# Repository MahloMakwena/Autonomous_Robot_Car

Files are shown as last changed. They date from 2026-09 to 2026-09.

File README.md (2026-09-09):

# Autonomous_Robot_Car
### Autonomous Path-Tracking Robot (RPLIDAR C1)

### Project Overview

This project focuses on designing and programming an **autonomous robotic vehicle** capable of dynamic path tracking, barrier mapping, and high-speed obstacle avoidance. Built on the **ESP32-S3 microcontroller architecture**, the robot uses real-time laser scanning data to safely navigate complex tracks without human intervention. 

###  How It Works

### 1. Environmental Mapping (The "Eyes")

* **Component:** Slamtec RPLIDAR C1 (2D DTOF Laser Scanner)
* **Execution:** The LiDAR emits thousands of laser pulses per second in a continuous **360-degree flat sweep**. It creates a real-time 2D coordinates map of track boundaries, walls, and upcoming curves up to 12 metres away.

### 2. Intelligent Path Decision (The "Brain")

* **Component:** ESP32-S3 Dual-Core Processor
* **Execution:** The processor ingests the live LiDAR data stream to calculate clear pathways ("gap finding"). Using an optimized navigation algorithm, the software dynamically adjusts steering vectors to guide the vehicle along the safest, fastest racing line.

### 3. Fail-Safe Emergency Cutoff (The "Shield")

* **Component:** 3-Button Hardware Latching Circuit & Interrupt Watchdog [disclaimer]
* **Execution:** For ultimate physical safety, the robot implements a true **hardware-level E-Stop loop**. Pressing the manual E-stop button breaks a self-holding relay circuit to instantly cut 100% of electrical power to the drive motors. Simultaneously, an isolated **3.3V logic signal** triggers a high-priority hardware interrupt on the ESP32-S3, forcing the software into a permanent safe halt mode until an engineer performs a manual system reset.

###  Tech Stack & Tools

* **Programming Language:** C++ (Embedded)
* **Framework:** Arduino IDE (ESP32 Arduino Core)
* **Hardware Design & Simulation:** Cirkit Designer

###  System Simulation & Architecture

To ensure high-fidelity safety testing before deploying code onto physical hardware, the system architecture was completely mapped out and simulated using **Cirkit Designer**: 

1. **The Latching Safety Loop:** We simulated a self-holding hardware latch circuit using standard DC relay modules, a Normally Closed (NC) button, and a Normally Open (NO) button. This layout guarantees power is cut mechanically to the motors during an emergency, entirely bypassing the processor.
2. **Logic Monitoring:** An isolated 3.3V logic line is mapped from the ESP32-S3 through a separate signal switch to GPIO 4, stabilized by a physical 10kΩ pull-down resistor to prevent pin floatation.
3. **Firmware Integration:** The Arduino sketch utilizes the Xtensa dual-core architecture of the ESP32-S3 to register a high-priority hardware interrupt (IRAM_ATTR). The software instantly drops the vehicle into a permanent safe state the exact millisecond a hardware shutdown occurs.

### ⚙️ Repository Structure

* **/src**: Core C++ firmware for the ESP32-S3, managing the hardware interrupt loops, LiDAR data parsing, and path-tracking logic.
* **/schematics**: Complete visual wiring blueprints and architecture maps designed in **Cirkit Designer**.

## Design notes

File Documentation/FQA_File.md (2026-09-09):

# Robo Rumble: Facilitator Q&A (FQ&A) Attendance Logbook

**Team Name:** Uniq
**Category:** Robo Grand Prix

*Instructions: To qualify for the 10 Bonus Points, log your attendance for every FQ&A session below. You must include a direct link to a screenshot proving your attendance (e.g., a screenshot of the meeting lobby or chat with your username visible).*

## Attendance Log

| Session Date | Time (Start-End) | Facilitator Name/Username | Our Key Takeaway / Question Asked | Proof of Attendance (Screenshot) |
| :--- | :--- | :--- | :--- | :--- |
| 2026-05-24 | 17:32 - 20:21 | senzo / VARZA | Asked about next steps after registration for Grand Prix car racing competition and whether we must buy own components or university will provide. Facilitator directed us to welcome channel in Robo Rumble Server. Clarified that we can start building after exams as Computer Systems Engineering TUT student. | [Link to image in repo](./FQA_Proof/senzo_chat.png) |
| 2026-08-28 | 20:04 - 20:04 | Donnel.M | Asked if Grand Prix challenge racing robots will race inside a walled path. Confirmed yes - robots will be placed inside walled path from start to finish line. This validated our wall-following + path tracking design with RPLidar C1 / Ultrasonic + Servo approach. | [Link to image in repo](./FQA_Proof/donnel_chat.png) |
| 2026-08-28 | 20:10 - 06:36 | +27 73 828 6493 (Robo Labs Bootcamp Facilitator) | Attended bootcamp on campus (TUT) and asked about Grand Prix walled path from start to finish line. Facilitator confirmed Yes. | [Link to image in repo](./FQA_Proof/whatsapp_bootcamp.png) |
| 2026-09-02 | 19:29 - 13:32 | Donnel.M / senzo | Asked if CAD design must be built from scratch or if we can assemble downloaded files from open source (A2Plus workbench). Facilitator advised to ask Robo Labs for final ruling. Takeaway: We will design custom U-brackets for JGB37 motors from scratch but can use open-source ESP32-S3 and L298N models with attribution. | [Link to image in repo](./FQA_Proof/donnel_chat.png) |

---

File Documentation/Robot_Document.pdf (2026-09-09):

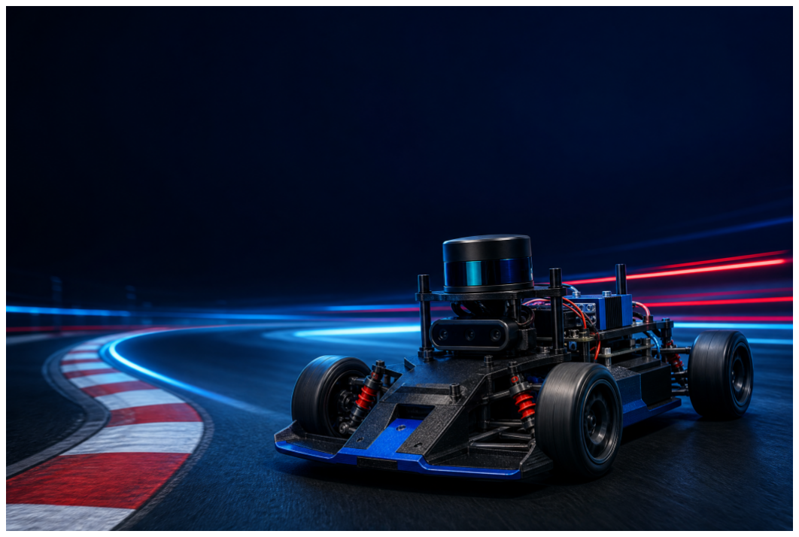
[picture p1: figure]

AUTONOMOUS RACING CAR • ESP32-S3 PROJECT REPORT • 2026

# AUTONOMOUS RACING CAR

Smart Sensors | Intelligent Control | Faster Tomorrow

## A 3D-Printed ESP32-S3 Autonomous Racing Car

Design, Build and Programming Documentation

Project Name : Autonomous Racing Car Main Controller : ESP32-S3
Course : Robotics & Embedded Systems Year : 2026

# Table of Contents

### 1. Project Overview 2. Objectives 3. Hardware Components 4. Bill of Materials 5. Software Requirements 6. System Architecture 7. Main Features 8. Project Structure 9. Installation Guide 10. Code Instructions 11. How to Run 12. Safety Notes 13. Future Improvements 14. Authors

## 1. Project Overview

The Autonomous Racing Car is an intelligent robotic vehicle designed to navigate a race track without continuous human control. It uses an ESP32-S3 as the main controller to process sensor information, control the motors, detect obstacles, calculate distances, and make decisions while racing.
The system combines a 360° LiDAR, wheel encoders, IMU, motor driver, steering servo and other sensors to allow the car to navigate safely and efficiently.
Key Idea
“Smart technology, precision control, maximum performance.”

## 2. Objectives

- Build a fully autonomous racing car.
- Use a 360° LiDAR to detect obstacles and other racing cars.
- Measure the distance between the car and obstacles.
- Calculate the distance traveled by the car using wheel encoders.
- Determine when the car needs to slow down before a turn.
- Automatically control steering and motor speed.
- Detect and avoid collisions.
- Navigate different turns on the racing track.
- Use the ESP32-S3 to control the complete system.
- Develop a reliable and responsive autonomous control system.

## 3. Hardware Components

- ESP32-S3 Development Board
- 360° LiDAR Sensor
- Motor Driver (L298N)
- DC Geared Motor (6V)
- Wheel Encoder
- IMU Sensor (MPU6050)
- Steering Servo Motor
- Ultrasonic Sensor (HC-SR04)
- Emergency-Stop Button
- Power Button
- Rechargeable Battery (7.4V/11.1V)
- Buck Converter (5V/3A)
- Wheels (x4)
- 3D-Printed Chassis
- Jumper Wires & Connectors

COMPONENT COSTING

## 4. Bill of Materials

No. | Component | Part Number / Model | Supplier | Qty | Unit Price (ZAR) | Total (ZAR)
1 | ESP32-S3 Dev Board | ESP32-S3-WROOM-1 | Seeed Studio | 1 | R 250 | R 250
2 | 360° LiDAR | RPLIDAR A1 | RobotShop | 1 | R 1,800 | R 1,800
3 | Motor Driver | L298N | Amazon | 1 | R 120 | R 120
4 | DC Geared Motor | TT 6V | Amazon | 2 | R 150 | R 300
5 | Wheel Encoder | QTR-8RC | RobotShop | 2 | R 100 | R 200
6 | IMU Sensor | MPU6050 | Amazon | 1 | R 80 | R 80
7 | Steering Servo | SG90 | Amazon | 1 | R 150 | R 150
8 | Ultrasonic Sensor | HC-SR04 | Amazon | 1 | R 70 | R 70
9 | Emergency-Stop | 22mm | RS Components | 1 | R 90 | R 90
10 | Power Button | PBS-110 | Amazon | 1 | R 50 | R 50
11 | Rechargeable Battery | 7.4V 2200mAh | Amazon | 1 | R 350 | R 350
12 | Buck Converter | LM2596 | Takealot | 1 | R 60 | R 60
13 | Wheels | 66mm | Takealot | 4 | R 60 | R 240
14 | 3D-Printed Chassis | Custom | Self-Design | 1 | R 400 | R 400
15 | Wires/Connectors | Jumper Kit | Takealot | 1 set | R 150 | R 150
Grand Total | | | | | | R 4,310

## 5. Software Requirements

- Arduino IDE
- ESP32 board support package
- C/C++ programming language
- LiDAR library / driver
- Servo motor library
- Encoder processing code
- IMU library
- Serial Monitor for debugging
- Git / GitHub (optional)

CONTROL SYSTEM

## 6. System Architecture

The ESP32-S3 acts as the main controller. It receives input from the 360° LiDAR (obstacle detection), wheel encoders (distance & speed), the IMU (orientation), and an ultrasonic sensor (backup). Based on this sensor data, it drives three outputs: the steering servo (angle control), the motor driver / DC motors (drive the wheels), and the emergency-stop system (safety).

AUTONOMY CAPABILITIES

## 7. Main Features

### Obstacle Detection

360° LiDAR continuously scans the surroundings and provides distance measurements.

### Distance Measurement

LiDAR measures distance to objects, while wheel encoders track how far the car has traveled.

### Automatic Steering

ESP32-S3 controls the steering servo according to the detected track direction.

### Speed Control

Motor speed is reduced before a turn or obstacle and increased after the turn.

### Collision Avoidance

Detects obstacles or other cars and takes action (slow down or change direction).

### Emergency Stop

Immediately disables the motors if an unsafe situation occurs.

SOFTWARE ORGANISATION

## 8. Project Structure

Autonomous-Racing-Car/
├── src/
│ └── main.cpp
├── sensors/
│ | ├── lidar.cpp
│ | ├── encoder.cpp
│ | ├── imu.cpp
│ | └── ultrasonic.cpp
├── motors/
│ | ├── motor_control.cpp
│ | └── steering.cpp
├── control/
│ | ├── obstacle_avoidance.cpp
│ | ├── speed_control.cpp
│ | └── turn_control.cpp
├── wiring/
│ └── wiring_diagram.png
├── CAD/
│ └── chassis/
└── documentation/
| └── project_report.pdf

SETUP WORKFLOW

## 9. Installation Guide

1. Install Arduino IDE — Download and install the Arduino IDE.
2. Add ESP32 Support — Open File → Preferences → Add Board Manager URL: https://dl.espressif.com/dl/package_esp32_index.json
3. Install ESP32 Board Package — Tools → Board → Boards Manager → Search for ESP32 and install.
4. Select the Board — Tools → Board → ESP32-S3 Dev Module.
5. Connect the ESP32-S3 — Use a USB cable.
6. Install Required Libraries — LiDAR, Servo, Encoder, Motor control.
7. Upload the Program — Open src/main.cpp, compile and upload.

CONTROL LOOP

## 10. Code Instructions

void loop() {
readLiDAR();
readEncoders();
readIMU();

calculateDistance();
calculateSpeed();

detectObstacles();
determineTurn();

controlSteering();
controlMotor();

checkEmergencyStop();
}
The ESP32-S3 repeatedly:
8. Reads the sensors
9. Calculates distances
10. Calculates speed and distance
11. Detects obstacles
12. Determines if a turn is approaching
13. Adjusts steering
14. Adjusts motor speed
15. Checks the emergency-stop system

TEST PROCEDURE

## 11. How to Run

- Place the car on a safe test surface.
- Check all wiring.
- Verify LiDAR data.
- Check wheel encoders.
- Test steering servo.
- Test motor driver (wheels lifted).
- Test emergency-stop button.
- Upload the program.
- Start the system.
- Begin at low speed.
- Increase speed after verifying all systems.

SAFE OPERATION

## 12. Safety Notes

- Always test at low speed first.
- Keep hands away from rotating wheels.
- Do not test near people, roads or hazards.
- Test the emergency-stop button.
- Ensure battery voltage is suitable.
- Do not connect motors to ESP32 GPIO pins directly.
- Use an appropriate motor driver.
- Make sure LiDAR and sensors are secure.
- Check for loose wires before every test.
- Disconnect the battery before changing wiring.
- Use proper battery protection.
- Never leave the car running unattended.

NEXT LAP

## 13. Future Improvements

- Higher-resolution LiDAR.
- Faster motor drivers.
- Better wheel encoders.
- GPS for outdoor navigation.
- Camera-based track recognition.
- Machine-learning obstacle detection.
- PID speed control.
- PID steering control.
- Automatic racing-line optimization.
- Wireless monitoring (phone/computer).
- Real-time telemetry.
- Automatic lap counting.
- Improved battery management.
- More advanced collision prediction.

PROJECT TEAM

## 14. Authors

Name | Role
| Project Lead
| Hardware & Electronics
| Software & Programming
| Mechanical / CAD Design
| Testing & Documentation
Institution: ______________________________
Course / Department: ______________________________ Year: 2026

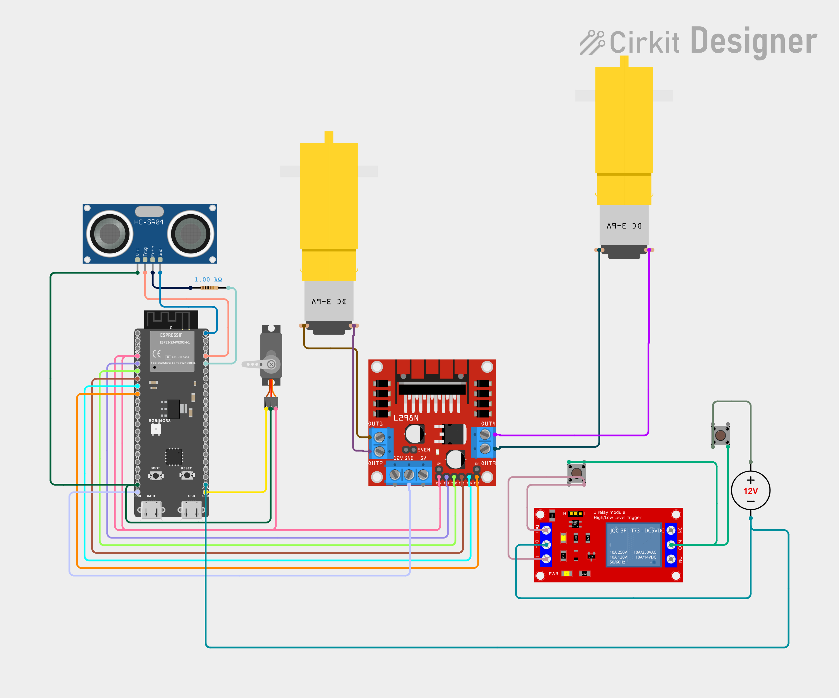
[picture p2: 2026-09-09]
CAD Designs/circuit_image.png

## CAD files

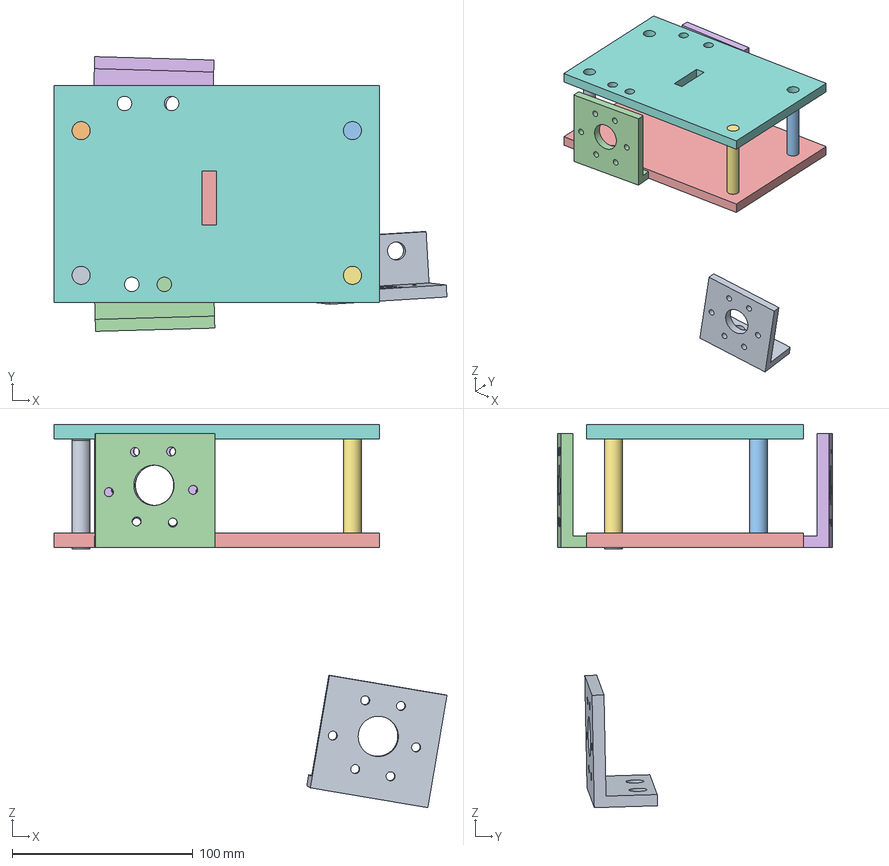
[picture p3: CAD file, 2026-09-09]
CAD Designs/Assembly.FCStd
217.3 x 151.9 x 211.9 mm
Screws_001
Screws_002
Screws_004
Motor_Mount_009
Chassis_Plate_004
Motor_Mount_011
Screws_006
Top_Chassis_001
Motor_Mount_014

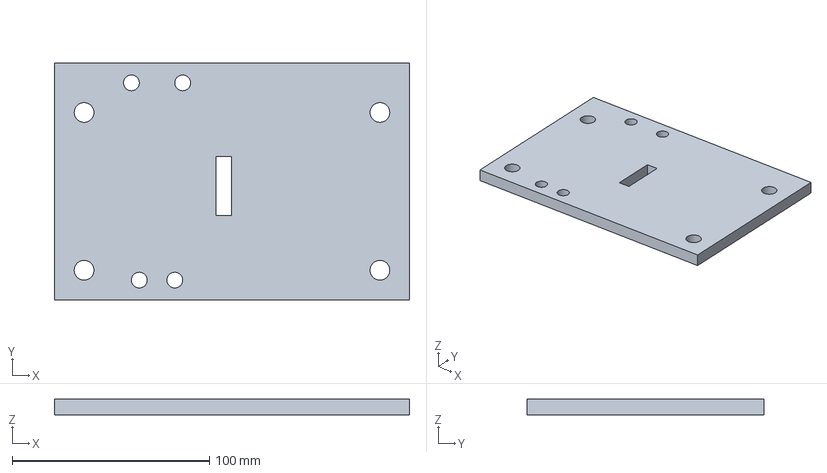
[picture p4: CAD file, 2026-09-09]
CAD Designs/Top_Chassis.FCStd
180.0 x 120.0 x 8.00 mm

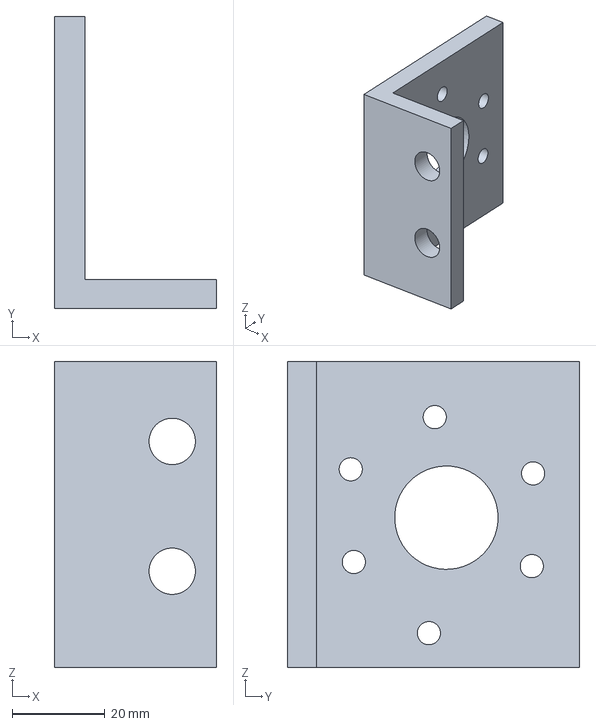
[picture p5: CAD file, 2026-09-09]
CAD Designs/Motor_Mount.FCStd
35.0 x 63.0 x 66.0 mm

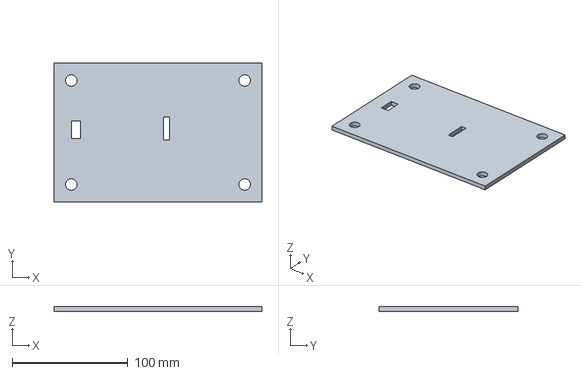
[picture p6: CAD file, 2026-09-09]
CAD Designs/Designed_Robot.FCStd
180.0 x 120.0 x 4.00 mm

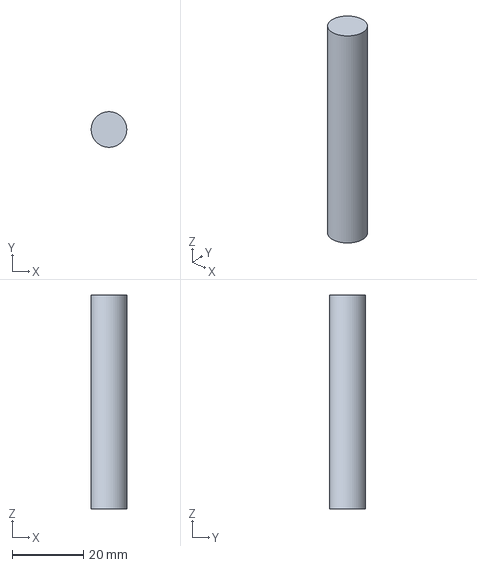
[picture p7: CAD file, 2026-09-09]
CAD Designs/Screws.FCStd
9.99 x 10.00 x 60.0 mm

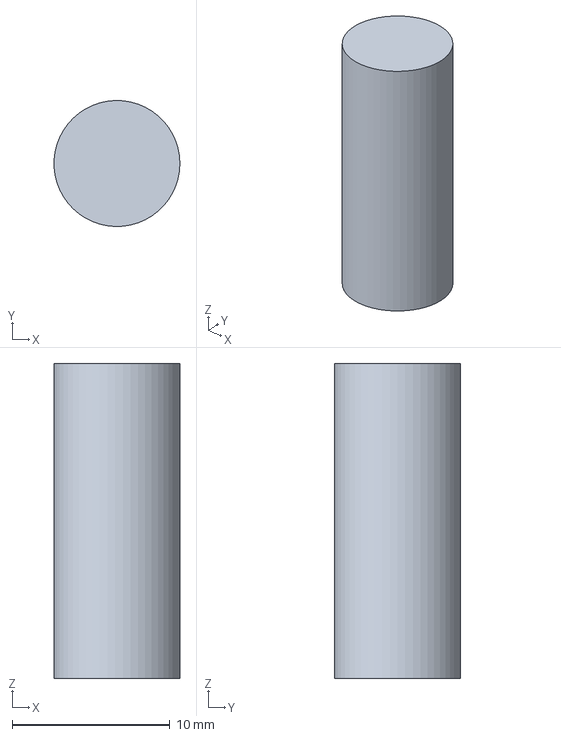
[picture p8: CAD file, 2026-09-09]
CAD Designs/small_screws.FCStd
7.99 x 8.00 x 20.0 mm

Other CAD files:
CAD Designs/Chassis_Plate.FCStd

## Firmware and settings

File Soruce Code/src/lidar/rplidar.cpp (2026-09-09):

/*
====================================================================
                 AUTONOMOUS RACING CAR
                     ESP32-S3 + RPLIDAR A1
====================================================================
*/

#include <Arduino.h>
#include <ESP32Servo.h>

// MOTOR PINS
const int LEFT_MOTOR_IN1 = 5;
const int LEFT_MOTOR_IN2 = 6;
const int LEFT_MOTOR_PWM = 7;
const int RIGHT_MOTOR_IN1 = 9;
const int RIGHT_MOTOR_IN2 = 10;
const int RIGHT_MOTOR_PWM = 8;

// STEERING
const int STEERING_SERVO_PIN = 4;
Servo steeringServo;
const int STEERING_CENTER = 90;
const int STEERING_LEFT = 55;
const int STEERING_RIGHT = 125;

// BUTTONS
const int START_BUTTON = 11;
const int POWER_BUTTON = 12;
const int ESTOP_BUTTON = 13;

// ENCODERS
const int LEFT_ENCODER_PIN = 14;
const int RIGHT_ENCODER_PIN = 15;
volatile long leftEncoderTicks = 0;
volatile long rightEncoderTicks = 0;

// RPLIDAR A1 UART
const int LIDAR_RX_PIN = 16;
const int LIDAR_TX_PIN = 17;
HardwareSerial LidarSerial(1);
const uint32_t LIDAR_BAUD = 115200;

// RPLIDAR COMMANDS
const uint8_t RPLIDAR_CMD_STOP = 0x25;
const uint8_t RPLIDAR_CMD_SCAN = 0x20;
const uint8_t RPLIDAR_CMD_RESET = 0x40;

// ENCODER SETTINGS
const float TICKS_PER_REVOLUTION = 20.0;
const float WHEEL_DIAMETER_MM = 65.0;
const float WHEEL_CIRCUMFERENCE_MM = PI * WHEEL_DIAMETER_MM;

// SPEED SETTINGS
int currentSpeed = 0;
const int MIN_SPEED = 80;
const int MAX_SPEED = 255;
const int ACCELERATION_STEP = 2;
const int DECELERATION_STEP = 8;

// LiDAR SETTINGS
const float SAFE_DISTANCE_CM = 50.0;
const float SLOW_DISTANCE_CM = 100.0;
const float TURN_DISTANCE_CM = 150.0;

// LiDAR DATA
float lidarDistance[360];
unsigned long lidarLastUpdate[360];

float frontDistance = 999.0;
float leftDistance = 999.0;
float rightDistance = 999.0;
float rearDistance = 999.0;

// RACING DATA
float totalDistance = 0.0;
float currentSpeedKmh = 0.0;

// CAR STATE
bool powerOn = false;
bool carRunning = false;
bool emergencyStop = false;
bool obstacleDetected = false;
bool turnAhead = false;

// TIMERS
unsigned long lastSpeedCalculation = 0;
unsigned long lastSensorAnalysis = 0;
unsigned long lastPrint = 0;

void IRAM_ATTR leftEncoderISR() {
    leftEncoderTicks++;
}

void IRAM_ATTR rightEncoderISR() {
    rightEncoderTicks++;
}

void setup() {
    Serial.begin(115200);
    delay(500);

    Serial.println();
    Serial.println("========================================");
    Serial.println("       AUTONOMOUS RACING CAR");
    Serial.println("       ESP32-S3 + RPLIDAR A1");
    Serial.println("========================================");

    initializePins();
    initializeMotors();
    initializeSteering();
    initializeEncoders();
    initializeButtons();
    initializeLidar();

    stopCar();
    centerSteering();

    Serial.println();
    Serial.println("SYSTEM READY");
    Serial.println("Press POWER button.");
}

void loop() {
    checkEmergencyStop();

    if (emergencyStop) {
        emergencyBrake();
        return;
    }

    checkPowerButton();

    if (!powerOn) {
        stopCar();
        return;
    }

    checkStartButton();

    if (!carRunning) {
        stopCar();
        return;
    }

    processLidar();
    updateEncoderDistance();
    calculateSpeed();

    if (millis() - lastSensorAnalysis >= 50) {
        lastSensorAnalysis = millis();
        updateDirectionDistances();
        detectObstacles();
        detectTurn();
    }

    autonomousDrive();
    printSensorData();

    delay(2);
}

void initializePins() {
    pinMode(LEFT_MOTOR_IN1, OUTPUT);
    pinMode(LEFT_MOTOR_IN2, OUTPUT);
    pinMode(RIGHT_MOTOR_IN1, OUTPUT);
    pinMode(RIGHT_MOTOR_IN2, OUTPUT);
    pinMode(LEFT_MOTOR_PWM, OUTPUT);
    pinMode(RIGHT_MOTOR_PWM, OUTPUT);
    Serial.println("Pins initialized.");
}

void initializeMotors() {
    ledcAttach(LEFT_MOTOR_PWM, 1000, 8);
    ledcAttach(RIGHT_MOTOR_PWM, 1000, 8);
    stopCar();
    Serial.println("Motors initialized.");
}

void initializeSteering() {
    steeringServo.attach(STEERING_SERVO_PIN);
    steeringServo.write(STEERING_CENTER);
    Serial.println("Steering initialized.");
}

void initializeEncoders() {
    pinMode(LEFT_ENCODER_PIN, INPUT_PULLUP);
    pinMode(RIGHT_ENCODER_PIN, INPUT_PULLUP);

    attachInterrupt(digitalPinToInterrupt(LEFT_ENCODER_PIN), leftEncoderISR, RISING);
    attachInterrupt(digitalPinToInterrupt(RIGHT_ENCODER_PIN), rightEncoderISR, RISING);

    Serial.println("Encoders initialized.");
}

void initializeButtons() {
    pinMode(START_BUTTON, INPUT_PULLUP);
    pinMode(POWER_BUTTON, INPUT_PULLUP);
    pinMode(ESTOP_BUTTON, INPUT_PULLUP);
    Serial.println("Buttons initialized.");
}

void initializeLidar() {
    LidarSerial.begin(
        LIDAR_BAUD,
        SERIAL_8N1,
        LIDAR_RX_PIN,
        LIDAR_TX_PIN
    );

    delay(100);

    while (LidarSerial.available()) {
        LidarSerial.read();
    }

    rplidarStop();
    delay(100);
    rplidarStart();

    Serial.println("RPLIDAR A1 initialized.");
}

void rplidarStop() {
    uint8_t command[] = {0xA5, RPLIDAR_CMD_STOP};
    LidarSerial.write(command, sizeof(command));
    LidarSerial.flush();
}

void rplidarReset() {
    uint8_t command[] = {0xA5, RPLIDAR_CMD_RESET};
    LidarSerial.write(command, sizeof(command));
    LidarSerial.flush();
    delay(100);
}

void rplidarStart() {
    uint8_t command[] = {0xA5, RPLIDAR_CMD_SCAN};
    LidarSerial.write(command, sizeof(command));
    LidarSerial.flush();
    delay(100);
}

void processLidar() {
    static uint8_t packet[5];
    static uint8_t packetIndex = 0;

    while (LidarSerial.available()) {
        uint8_t b = LidarSerial.read();

        if (packetIndex == 0) {
            if ((b & 0x01) == 0) {
                continue;
            }

            packet[0] = b;
            packetIndex = 1;
            continue;
        }

        packet[packetIndex] = b;
        packetIndex++;

        if (packetIndex >= 5) {
            packetIndex = 0;

            bool startBit = packet[0] & 0x01;
            bool inverseStartBit = packet[0] & 0x02;

            if (startBit == inverseStartBit) {
                continue;
            }

            uint8_t quality = packet[0] >> 2;

            if (quality == 0) {
                continue;
            }

            uint16_t angleRaw =
                packet[1] |
                (packet[2] << 8);

            float angle = (angleRaw >> 1) / 64.0;

            uint16_t distanceRaw =
                packet[3] |
                (packet[4] << 8);

            float distanceMM = distanceRaw / 4.0;
            float distanceCM = distanceMM / 10.0;

            if (angle < 0 || angle >= 360) {
                continue;
            }

            if (distanceCM <= 0 || distanceCM > 1200) {
                continue;
            }

            int index = (int)angle;

            if (index >= 0 && index < 360) {
                lidarDistance[index] = distanceCM;
                lidarLastUpdate[index] = millis();
            }
        }
    }
}

float getDistanceAtAngle(int angle) {
    angle = angle % 360;

    if (angle < 0) {
        angle += 360;
    }

    if (millis() - lidarLastUpdate[angle] > 500) {
        return 999.0;
    }

    return lidarDistance[angle];
}

float getMinimumDistance(int startAngle, int endAngle) {
    float minimumDistance = 999.0;

    if (startAngle <= endAngle) {
        for (int angle = startAngle; angle <= endAngle; angle++) {
            float distance = getDistanceAtAngle(angle);

            if (distance < minimumDistance) {
                minimumDistance = distance;
            }
        }
    } else {
        for (int angle = startAngle; angle < 360; angle++) {
            float distance = getDistanceAtAngle(angle);

            if (distance < minimumDistance) {
                minimumDistance = distance;
            }
        }

        for (int angle = 0; angle <= endAngle; angle++) {
            float distance = getDistanceAtAngle(angle);

            if (distance < minimumDistance) {
                minimumDistance = distance;
            }
        }
    }

    return minimumDistance;
}

void updateDirectionDistances() {
    frontDistance = getMinimumDistance(345, 15);
    rightDistance = getMinimumDistance(75, 105);
    rearDistance = getMinimumDistance(165, 195);
    leftDistance = getMinimumDistance(255, 285);
}

void detectObstacles() {
    obstacleDetected = frontDistance <= SAFE_DISTANCE_CM;
}

void detectTurn() {
    if (frontDistance < TURN_DISTANCE_CM) {
        turnAhead =
            leftDistance > frontDistance + 20 ||
            rightDistance > frontDistance + 20;
    } else {
        turnAhead = false;
    }
}

void setMotorPWM(int leftPWM, int rightPWM) {
    leftPWM = constrain(leftPWM, 0, 255);
    rightPWM = constrain(rightPWM, 0, 255);

    ledcWrite(LEFT_MOTOR_PWM, leftPWM);
    ledcWrite(RIGHT_MOTOR_PWM, rightPWM);
}

void moveForward(int speed) {
    speed = constrain(speed, 0, 255);

    digitalWrite(LEFT_MOTOR_IN1, HIGH);
    digitalWrite(LEFT_MOTOR_IN2, LOW);

    digitalWrite(RIGHT_MOTOR_IN1, HIGH);
    digitalWrite(RIGHT_MOTOR_IN2, LOW);

    setMotorPWM(speed, speed);
}

void moveReverse(int speed) {
    speed = constrain(speed, 0, 255);

    digitalWrite(LEFT_MOTOR_IN1, LOW);
    digitalWrite(LEFT_MOTOR_IN2, HIGH);

    digitalWrite(RIGHT_MOTOR_IN1, LOW);
    digitalWrite(RIGHT_MOTOR_IN2, HIGH);

    setMotorPWM(speed, speed);
}

void stopCar() {
    setMotorPWM(0, 0);

    digitalWrite(LEFT_MOTOR_IN1, LOW);
    digitalWrite(LEFT_MOTOR_IN2, LOW);

    digitalWrite(RIGHT_MOTOR_IN1, LOW);
    digitalWrite(RIGHT_MOTOR_IN2, LOW);
}

void steerLeft() {
    steeringServo.write(STEERING_LEFT);
}

void steerRight() {
    steeringServo.write(STEERING_RIGHT);
}

void centerSteering() {
    steeringServo.write(STEERING_CENTER);
}

void turnLeft(int speed) {
    steerLeft();
    moveForward(speed);
}

void turnRight(int speed) {
    steerRight();
    moveForward(speed);
}

void increaseSpeed() {
    currentSpeed += ACCELERATION_STEP;

    if (currentSpeed > MAX_SPEED) {
        currentSpeed = MAX_SPEED;
    }
}

void decreaseSpeed() {
    currentSpeed -= DECELERATION_STEP;

    if (currentSpeed < MIN_SPEED) {
        currentSpeed = MIN_SPEED;
    }
}

void emergencyBrake() {
    currentSpeed = 0;
    stopCar();
    centerSteering();
}

void controlSpeed() {
    if (frontDistance <= SAFE_DISTANCE_CM) {
        currentSpeed = 0;
        return;
    }

    if (frontDistance <= SLOW_DISTANCE_CM) {
        decreaseSpeed();
        return;
    }

    if (turnAhead) {
        decreaseSpeed();
        return;
    }

    increaseSpeed();
}

void updateEncoderDistance() {
    static long previousLeftTicks = 0;
    static long previousRightTicks = 0;

    long leftTicks;
    long rightTicks;

    noInterrupts();
    leftTicks = leftEncoderTicks;
    rightTicks = rightEncoderTicks;
    interrupts();

    long leftDifference = leftTicks - previousLeftTicks;
    long rightDifference = rightTicks - previousRightTicks;

    previousLeftTicks = leftTicks;
    previousRightTicks = rightTicks;

    float averageTicks =
        (leftDifference + rightDifference) / 2.0;

    float revolutions =
        averageTicks / TICKS_PER_REVOLUTION;

    float distanceMM =
        revolutions * WHEEL_CIRCUMFERENCE_MM;

    totalDistance += distanceMM / 1000.0;
}

void calculateSpeed() {
    unsigned long now = millis();

    if (now - lastSpeedCalculation < 100) {
        return;
    }

    static float previousDistance = 0;

    float distanceDifference =
        totalDistance - previousDistance;

    previousDistance = totalDistance;

    currentSpeedKmh =
        distanceDifference * 10.0 * 3.6;

    lastSpeedCalculation = now;
}

void resetDistance() {
    totalDistance = 0;

    noInterrupts();
    leftEncoderTicks = 0;
    rightEncoderTicks = 0;
    interrupts();

    Serial.println("Distance reset.");
}

int chooseAvoidanceDirection() {
    if (
        leftDistance > SAFE_DISTANCE_CM &&
        leftDistance > rightDistance
    ) {
        return -1;
    }

    if (
        rightDistance > SAFE_DISTANCE_CM &&
        rightDistance > leftDistance
    ) {
        return 1;
    }

    if (leftDistance > SAFE_DISTANCE_CM) {
        return -1;
    }

    if (rightDistance > SAFE_DISTANCE_CM) {
        return 1;
    }

    return 0;
}

void avoidObstacle() {
    currentSpeed = MIN_SPEED;

    int direction = chooseAvoidanceDirection();

    if (direction == -1) {
        Serial.println("OBSTACLE -> LEFT");
        steerLeft();
        moveForward(MIN_SPEED);
    } else if (direction == 1) {
        Serial.println("OBSTACLE -> RIGHT");
        steerRight();
        moveForward(MIN_SPEED);
    } else {
        Serial.println("OBSTACLE -> STOP");
        emergencyBrake();
    }
}

void handleTurn() {
    if (leftDistance > rightDistance) {
        turnLeft(currentSpeed);
    } else {
        turnRight(currentSpeed);
    }
}

void autonomousDrive() {
    if (emergencyStop) {
        emergencyBrake();
        return;
    }

    if (frontDistance <= SAFE_DISTANCE_CM) {
        emergencyBrake();
        avoidObstacle();
        return;
    }

    if (turnAhead) {
        controlSpeed();
        handleTurn();
        return;
    }

    controlSpeed();

    centerSteering();
    moveForward(currentSpeed);
}

void checkStartButton() {
    static bool lastState = HIGH;

    bool state = digitalRead(START_BUTTON);

    if (lastState == HIGH && state == LOW) {
        if (powerOn && !emergencyStop) {
            carRunning = !carRunning;

            if (carRunning) {
                currentSpeed = MIN_SPEED;
                Serial.println("RACING STARTED");
            } else {
                currentSpeed = 0;
                stopCar();
                centerSteering();
                Serial.println("RACING STOPPED");
            }
        }

        delay(50);
    }

    lastState = state;
}

void checkPowerButton() {
    static bool lastState = HIGH;

    bool state = digitalRead(POWER_BUTTON);

    if (lastState == HIGH && state == LOW) {
        powerOn = !powerOn;

        if (powerOn) {
            Serial.println("POWER ON");
            currentSpeed = 0;
        } else {
            Serial.println("POWER OFF");
            carRunning = false;
            currentSpeed = 0;
            stopCar();
            centerSteering();
        }

        delay(50);
    }

    lastState = state;
}

void checkEmergencyStop() {
    if (digitalRead(ESTOP_BUTTON) == LOW) {
        if (!emergencyStop) {
            emergencyStop = true;
            carRunning = false;
            currentSpeed = 0;
            stopCar();
            centerSteering();

            Serial.println();
            Serial.println("!!!!!!!!!!!!!!!!!!!!!!!!");
            Serial.println("!!! EMERGENCY STOP !!!");
            Serial.println("!!!!!!!!!!!!!!!!!!!!!!!!");
        }
    }
}

void resetEmergencyStop() {
    if (digitalRead(ESTOP_BUTTON) == HIGH) {
        emergencyStop = false;
        currentSpeed = 0;
        centerSteering();
        Serial.println("Emergency stop reset.");
    }
}

void printSensorData() {
    unsigned long now = millis();

    if (now - lastPrint < 500) {
        return;
    }

    lastPrint = now;

    Serial.println();
    Serial.println("================================");
    Serial.println("          CAR STATUS");
    Serial.println("================================");

    Serial.print("Power: ");
    Serial.println(powerOn ? "ON" : "OFF");

    Serial.print("Running: ");
    Serial.println(carRunning ? "YES" : "NO");

    Serial.print("Emergency: ");
    Serial.println(emergencyStop ? "YES" : "NO");

    Serial.println("--------------------------------");

    Serial.print("Front: ");
    Serial.print(frontDistance, 1);
    Serial.println(" cm");

    Serial.print("Left: ");
    Serial.print(leftDistance, 1);
    Serial.println(" cm");

    Serial.print("Right: ");
    Serial.print(rightDistance, 1);
    Serial.println(" cm");

    Serial.print("Rear: ");
    Serial.print(rearDistance, 1);
    Serial.println(" cm");

    Serial.println("--------------------------------");

    Serial.print("Distance: ");
    Serial.print(totalDistance, 3);
    Serial.println(" m");

    Serial.print("Speed: ");
    Serial.print(currentSpeedKmh, 2);
    Serial.println(" km/h");

    Serial.print("Motor PWM: ");
    Serial.println(currentSpeed);

    Serial.print("Obstacle: ");
    Serial.println(obstacleDetected ? "YES" : "NO");

    Serial.print("Turn: ");
    Serial.println(turnAhead ? "YES" : "NO");

    Serial.println("================================");
}

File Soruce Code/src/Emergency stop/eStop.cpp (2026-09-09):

void loop() {
      // Check if the hardware interrupt flag was tripped
  if (estopTriggered) 
  {
    // 1. Instantly write software failsafes (e.g., turn off software PWM signals)
        analogWrite(motorPin1, 0); 
        analogWrite(motorPin2, 0); 
    // 2. Lock the software loop permanently until an engineer resets the board
    while (true) 
    {
      Serial.println("!!! SOFTWARE ALERT: HARDWARE E-STOP DETECTED !!!");
      delay(1000); 
    }
  }

  // Your normal autonomous path-tracking or navigation code runs here
  Serial.println("Autonomous vehicle in race.....");
  delay(500); 
  // Move motor forward
  moveForward();
  // Stop
  stop();
  // Move motor backward
   //backward();
  // Stop
  stop();
}

//helper functions for robot motion
void backward()// allows robot to move backwards
{
  Serial.println("Moving backwards....");
  digitalWrite(motorPin1, LOW);
  digitalWrite(motorPin2, HIGH);
  ledcWrite(enablePin, dutyCycle);
  delay(2000);
}
void stop()// stop the robot
{
  Serial.println("Motor Stopped");
  digitalWrite(motorPin1, LOW);
  digitalWrite(motorPin2, LOW);
  delay(1000);
}
void moveForward()// allows robot to move forward
{
  Serial.println("Moving forward...");
  digitalWrite(motorPin1, HIGH);
  digitalWrite(motorPin2, LOW);
  ledcWrite(enablePin, dutyCycle);
  delay(2000);
}
bool isPath(float right,float forward)//function that checks which direction to take
{
    /*get distance from both sides using a lidar
    //store distance from position to right wall
    //and also store distance from current position to distance ahead
    // compare the distances with unstored calculated left distance
    //the robot moves in the direction with longest distance
    (long distance simply implies that no wall detected)
    */ 
    bool isGo = false;

}
void turnLeft()//turn left
{

}
void turnRight()//go right
{

}
